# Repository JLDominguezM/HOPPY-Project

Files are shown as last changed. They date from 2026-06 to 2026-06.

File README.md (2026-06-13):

# HOPPY: a one-legged hopping robot







MuJoCo simulation and physical implementation of HOPPY, a one-legged robot that
hops around a rotating boom. The project starts from the
[HOPPY educational kit from the University of Illinois](https://github.com/RoboDesignLab/HOPPY-Project)
(Ramos et al., [arXiv:2010.14580](https://arxiv.org/abs/2010.14580)) and adds a
mechanical redesign of our own: a bird-type leg with a four-bar knee, 3D-printed
parts and PVC tubes.

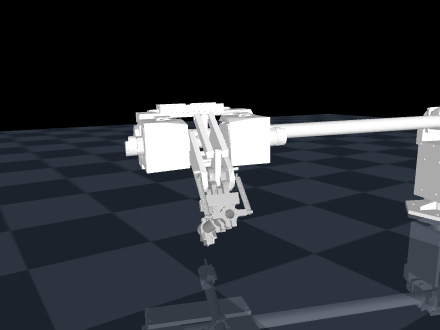
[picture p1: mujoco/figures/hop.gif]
HOPPY hopping in MuJoCo


On hardware the robot hops on its own, continuously: 64 hops logged by its own
telemetry, 0.27 s of flight per hop and roughly 9 cm of apex. That flight time
is close to the simulation (about 0.33 s per hop).

The same controller in simulation, frame by frame, advancing around the post:

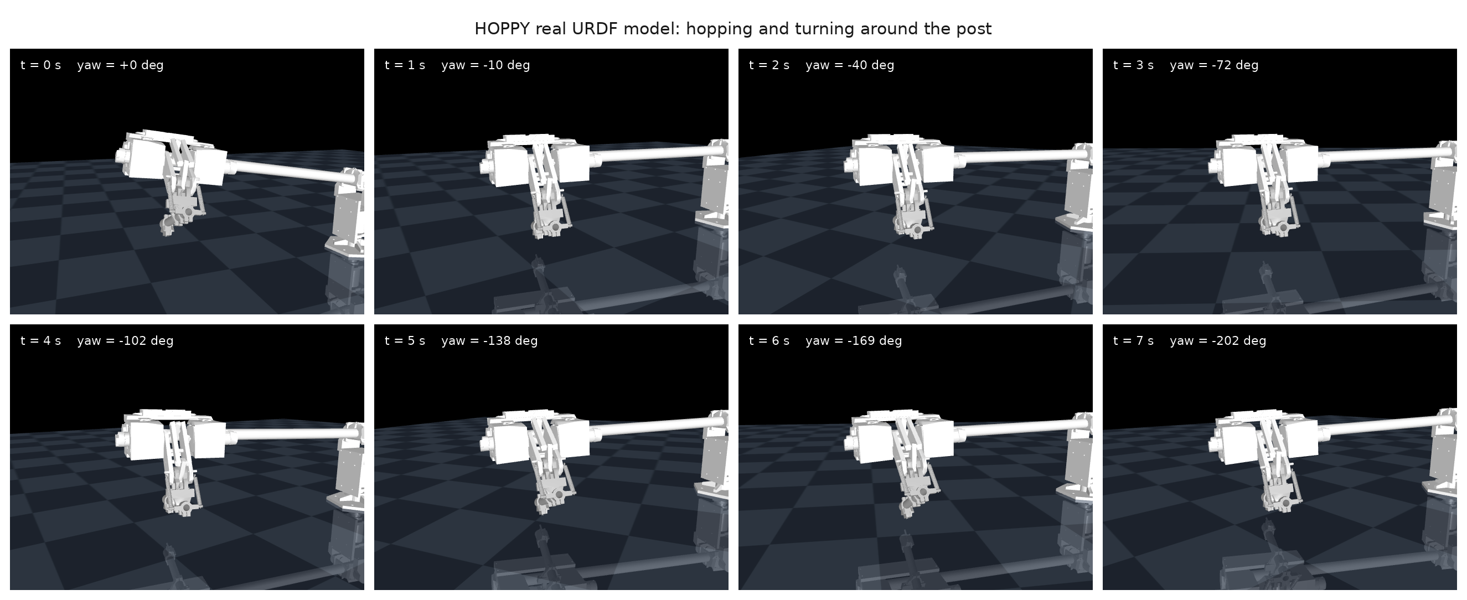
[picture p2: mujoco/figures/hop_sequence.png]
Frames over 7 seconds; the boom advances around the post


## Contents

- [Repository layout](#repository-layout)
- [Simulation (mujoco/)](#simulation-mujoco)
- [Physical parameters and where they come from](#physical-parameters-and-where-they-come-from)
- [Firmware (Microcontroller/)](#firmware-microcontroller)
- [Validation and results](#validation-and-results)
- [Known limitations](#known-limitations)
- [MATLAB simulator on Linux](#matlab-simulator-on-linux)
- [References](#references)
- [Authors](#authors)

## Repository layout

| Folder | Contents |
|---|---|
| [`mujoco/`](mujoco/README.md) | Full MuJoCo simulation: three models, the hybrid controller, a verification suite and the analysis scripts |
| [`Microcontroller/`](Microcontroller/README.md) | C2000 firmware (LaunchPad F28379D) for the physical robot: real-time control at 1 kHz |
| [`CAD/`](CAD/STL_imprimir/README.md) | Redesign assembly (SolidWorks/STEP), nominal parameters and the parts to print |
| [`Simulator_MATLAB/`](Simulator_MATLAB/README.md) | Original MATLAB simulator from the paper, used as the validation reference |

## Simulation (mujoco/)

Requirements: Python 3 with `mujoco`, `numpy` and `matplotlib`.

### The three models

The project grew through three models, each with its own purpose.

| Model | File | Geometry | Hop (steady regime) | Purpose |
|---|---|---|---|---|
| Abstract | `tune_eval.py` | simplified (anchored to `get_params.m`) | body rises 7.2 cm | validation against the paper's MATLAB |
| CAD twin | `twin.py` | dimensions, masses and inertias measured from the CAD | body rises 5.6 cm | structural fidelity to the redesign |
| Real URDF | `hoppy_urdf.py` | exported from SolidWorks (sw2urdf) | foot clears 4.5 cm, turns around the post | the model that runs the robot's controller |

The three share the same controller (`controller.py`), a faithful port of the
paper's MATLAB simulator: a FLIGHT/STANCE state machine at 1 kHz, Cartesian foot
control through the transposed Jacobian in flight, a Bezier reaction-force
profile in stance, a voltage-based actuator model with back-EMF and saturation,
and a velocity estimate from a filtered derivative (encoder emulation).

### Control architecture

The controller is a hybrid state machine. Touchdown and lift-off are detected
from the contact force.

```mermaid
stateDiagram-v2
    [*] --> FLIGHT
    FLIGHT --> STANCE: touchdown (contact force over threshold)
    STANCE --> FLIGHT: liftoff (GRF below 1.5 N, or end of Tst)
```

Every control step runs at 1 kHz, the same loop in simulation and on the
firmware:

```mermaid
flowchart LR
    R[Read encoders] --> V[Filtered velocity, lambda = 10]
    V --> P{Phase}
    P -- FLIGHT --> A[Cartesian foot PD<br/>u = J^T F]
    P -- STANCE --> S[Bezier reaction force<br/>u = -J^T Fx,Fz + soft joint PD]
    A --> M[Voltage, back-EMF and saturation<br/>12 V and 9.2 A]
    S --> M
    M --> W[PWM to the motors]
```

### How to run

| What | Command |
|---|---|
| Watch the real URDF hopping | `python3 view_hop_urdf.py --viewer` |
| Watch the CAD twin hopping | `python3 view_twin.py` |
| Verify the abstract model against MATLAB | `python3 verify.py` |
| Verify the twin | `python3 -c "import twin; from verify import verify; verify(dict(twin.DEFAULTS), mdl=twin)"` |
| Component check of the twin | `python3 twin_check.py` |
| Signals from every phase | `python3 plot_signals.py` |
| Mechanical-model ablation | `python3 ablation.py` |
| Integrator comparison | `python3 integrators.py` |
| Renders and videos (headless) | `MUJOCO_GL=egl python3 render_twin.py` |

`verify.py` is strict on purpose. It asks for real push-off (the contact force
actually loads), a flight phase, no foot flutter and a stable limit cycle. A
metric that only counts foot lift-offs accepts degenerate solutions, such as a
leg that flutters without hopping. This suite does not.

## Physical parameters and where they come from

### Leg geometry (measured from the CAD and the nominal-parameters document)

| Constant | Value | What it is |
|---|---|---|
| `LH` | 0.096 m | thigh length (hip axis to knee axis) |
| `LK` | 0.1545 m | shank length (tube) |
| `DK` | 0.052 m | lateral offset of the tube from the knee axis |
| `LKF` | 0.1635 m | effective shank, `sqrt(LK^2 + DK^2)` |
| `LB`, `DB`, `HB` | 0.687, 0.187, 0.250 m | boom: pivot-to-hip, lateral offset, pivot height |

The redesigned leg is bird-type (mirrored from the original HOPPY): the knee
points backward, and bending it drives the foot forward. The tube never lines up
with the thigh; at full extension it already sits at about 134 degrees to it.

### Actuators (goBILDA 5202 datasheet, Yellow Jacket series)

| Constant | Value | Reason |
|---|---|---|
| `NH` | 26.9 | hip motor reduction |
| `NK` | 28.8 | effective knee reduction (the encoder scale turns the physical 26.9 into an effective 28.8, which matches the kit's nominal document) |
| `Rw` | 1.3 ohm | armature resistance |
| `kT` | 0.0135 N m/A | torque constant |
| `kv` | 0.0186 V s/rad | back-EMF constant |
| `VMAX`, `IMAX` | 12 V, 9.2 A | real electrical limits; they set the maximum torque kT * N * IMAX (3.3 to 3.6 N m per joint) |

Two effects follow from these constants, and the simulation models both
explicitly.

- **Reflected rotor inertia** (`armature = N^2 * Ir`, with `Ir = 7e-6 kg m^2`).
  Without it the accelerations are unrealistic: the ablation shows the robot
  "hops" 67 percent higher when armature is removed.
- **Equivalent actuator damping** (`damping = 0.5 * kT^2 * N^2 / Rw`). This is
  the motor's electrical dissipation reflected to the joint. The 0.5 keeps it
  from double-counting the dissipation the voltage model already adds. It is not
  a hand-tuned number; it comes from the electrical model.

Saturation is not a torque clip. The controller turns desired torque into
voltage (`V = Rw/(kT N) tau + kv N qdot`), clips that to 12 V, computes the
current against the back-EMF, clips it to 9.2 A, and only then gets the applied
torque. The limit therefore depends on speed, the same way it does in the real
motor.

### Knee spring

The real robot carries two tension springs (Ks = 1.67 kN/m, L0 = 80 mm) in a
series-elastic arrangement through the four-bar. In the model this is a joint
spring (`stiffness` plus `springref` at the knee). A faithful series-elastic
spring leaves the knee almost rigid under this controller (the paper uses a
controller designed to exploit it). The trade-off is documented, and the
ablation measures the effect of the joint spring that is used.

### Foot-ground contact

| Parameter | Value | Reason |
|---|---|---|
| `solref` | 0.0191 1 | hard contact, no numerical bounce |
| `solimp` | 0.95 0.99 0.001 | sub-millimeter penetration |
| `friction` | 2.0 | the real foot is a rubber tip and must not slip during push-off |
| integrator | `implicitfast`, 1 ms step | integrates the velocity-dependent terms implicitly (damping and armature, exactly what this model adds); `integrators.py` shows that RK4 with the recommended settings produces the same hop |

Touchdown and lift-off are detected from the normal contact force against a
threshold. This is the same criterion the physical robot uses, where the foot
sensor (a SoftPot) was calibrated on the bench: 0 in the air, around 200 when
grazing, 2870 loaded at rest and 4095 at full load, with the threshold at 2048.

### Controller (constants from the paper's MATLAB simulator)

| Constant | Value | Role |
|---|---|---|
| `Kp_sw`, `Kd_sw` | 150, 5 | Cartesian foot PD in flight (N/m, N s/m) |
| `Krh` | 0.10 | Raibert-style foot placement |
| `Tst` | 0.35 s | nominal stance duration |
| `Fz_bz` | [0, 20, 100, 0, 0] | Bezier control points for the vertical force (desired peak 42.8 N) |
| `Fx_bz` | [0, 0, -25, 0, 0] | tangential push; its sign sets the direction of travel |
| `Kp_st`, `Kd_st` | 0.03, 0.08 | soft joint PD in stance (regularizer) |
| blending | 10 ms | flight-to-stance blend so no torque steps appear |
| `lambda` | 10 rad/s | filter for the estimated velocity (encoder emulation) |

## Firmware (Microcontroller/)

Firmware for the LaunchPad F28379D (C2000), built on the original kit example,
running the same controller from the paper at 1 kHz. Toolchain: Code Composer
Studio 12.8, C2000 compiler 22.6, SYS/BIOS. The active file is
`blinky_rtos_flash/cpu01/cpu01_main.c`.

Implementation notes:

- **Bird-type kinematics**: mirrored-branch IK and a polynomial map of the
  four-bar knee, `q_knee = KA e^2 + KB e + KC` with `KA = -0.454`, `KB = -1.534`,
  `KC = 0.80`, calibrated on the bench with a plumb line and photos. The
  mechanism's effective ratio runs from 1.5 at extension to 0.7 at flexion; the
  negative sign reflects the mirrored morphology. Knee torque is mapped by
  virtual work using the derivative of the same polynomial.
- **Motor electrical model in the loop** (the same equation as the sim): desired
  torque to voltage with back-EMF compensation, then to PWM with the 12 V bus as
  the scale.
- **Continuous-hop state machine** (`JUMP_MODE`): touchdown on the foot-sensor
  edge with debounce, Bezier push in stance, early lift-off when the sensor
  unloads, and an aerial recovery to the landing pose.
- **On-board telemetry**, readable live through CCS Expressions: hop counter,
  duration of the last flight (apex height is g t^2 / 8), measured duration of
  the last stance, and the peaks of PWM and knee travel per push.
- Safety: a motor flag, a PWM limit adjustable live, and a startup with inert
  values.

The robot is balanced with a counterweight on the boom (5 kg at 19 cm in the
current setup), tuned with the float-point method: find the distance that leaves
the boom neutral, then mount the weight at about 76 percent of it, because a full
balance leaves the leg with no weight to load it.

## Validation and results

- **Against the paper's MATLAB**: the `verify.py` suite passes 12 of 12 checks,
  reproducing the behavior of the original simulator.
- **Ablation** (`mujoco/figures/ablation.png`): measures the effect of armature,
  damping, spring and saturation on the hop. Without saturation the ideal
  actuator asks for 13.2 A against the 9.2 A the motor actually has.
- **On hardware**: autonomous continuous hopping in place, 64 hops logged, 0.27 s
  of flight per hop, motors working inside their limits.

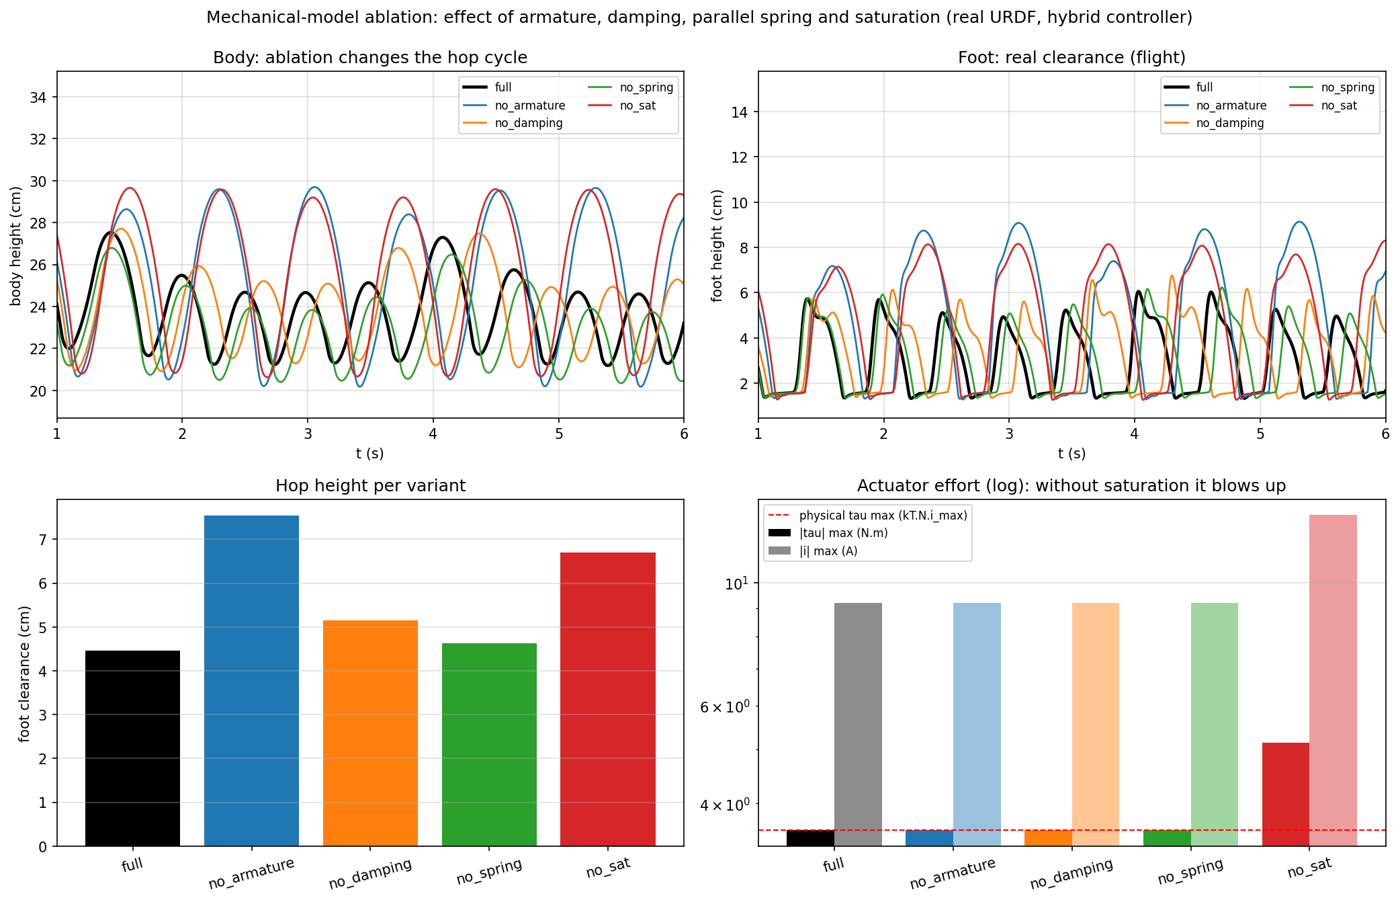
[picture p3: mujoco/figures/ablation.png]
Mechanical-model ablation


### Simulation vs hardware

Everything below is measured, not assumed.

| Metric | Simulation | Real robot |
|---|---|---|
| Control loop | 1 kHz | 1 kHz (C2000) |
| Contact detection | GRF over threshold | SoftPot over 2048 |
| Velocity filter | lambda = 10 | lambda = 10 |
| Counterweight moment | 1.00 kg m | 0.95 kg m |
| Flight per hop | about 0.33 s | 0.27 s |
| Continuous hopping | stable limit cycle | 64 hops logged |

## Known limitations

- Travel around the post under the tangential push is limited by the stiffness of
  the gantry post, which moves under the sustained lateral force. This is a
  structural issue, not a control one.
- A faithful series-elastic spring needs a controller designed for it (such as
  the one in the original paper); under this controller the soft joint spring is
  used instead.
- The foot sensor reports the position of the pressure point, not force, so the
  contact threshold was calibrated empirically.

## MATLAB simulator on Linux

The reference simulator runs on MATLAB R2026a:

```bash
cd Simulator_MATLAB
matlab        # inside the interface, run: MAIN
```

## References

- J. Ramos, Y. Ding, Y. Sim, K. Murphy, D. Block. "HOPPY: An open-source kit for
  education with dynamic legged robots". arXiv:2010.14580.
- Original kit and code: [RoboDesignLab/HOPPY-Project](https://github.com/RoboDesignLab/HOPPY-Project).
- MuJoCo and the official MJCF documentation.

### How to cite

A `CITATION.cff` file is included, so GitHub shows a "Cite this repository"
button. In BibTeX:

```bibtex
@software{hoppy_redesign_2026,
  author = {Dom\'inguez Morales, Jos\'e Luis and Tovar Mendoza, H\'ector Eduardo
            and Velarde Barr\'on, Jocelyn Anahid and Llamas Hern\'andez, Paola
            and Mac Beath Mili\'an, Pablo Armando},
  title  = {HOPPY redesign: MuJoCo simulation and physical implementation},
  year   = {2026},
  url    = {https://github.com/JLDominguezM/HOPPY-Project}
}

@article{ramos2020hoppy,
  author  = {Ramos, Joao and Ding, Yanran and Sim, Young-woo and Murphy, Kevin
             and Block, Daniel},
  title   = {{HOPPY}: An open-source kit for education with dynamic legged robots},
  journal = {arXiv preprint arXiv:2010.14580},
  year    = {2020}
}
```

See [NOTICE](NOTICE) for attribution and [LICENSE](LICENSE) for terms of use.

## Authors

Héctor Eduardo Tovar Mendoza, Jocelyn Anahid Velarde Barrón, Paola Llamas
Hernández, José Luis Domínguez Morales, Pablo Armando Mac Beath Milián.

Robotics Implementation, June 2026.

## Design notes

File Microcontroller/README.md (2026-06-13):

# Firmware (TI C2000)

Real-time control firmware for the physical HOPPY, running on a TI LaunchPad
F28379D (C2000 Delfino) under SYS/BIOS. The control loop runs at 1 kHz and is
the same controller as the simulation (see the top-level README and `mujoco/`).

## Layout

- `blinky_rtos_flash/` — the Code Composer Studio project (CPU1 + CPU2).
  - `cpu01/cpu01_main.c` — **the active file**: the full HOPPY controller.
  - `cpu02/` — second core, unused by the controller.
- `cpu01_main_EXAMPLE.c` — the original kit example (motor and sensor test).
- `cpu01_main_PRUEBA_LENTA.c` — a slow bench-test variant, kept for reference.

## Toolchain and hardware

- Code Composer Studio 12.8, TI C2000 compiler 22.6, SYS/BIOS.
- 2x goBILDA 5202 motors driven by VNH5019 H-bridges, quadrature encoders on
  EQEP1/EQEP2, and a SoftPot foot sensor on ADC-D0.

## Build and flash

1. In Code Composer Studio, import `blinky_rtos_flash/` as an existing CCS
   project (File > Import > CCS Projects).
2. Work in `cpu01/cpu01_main.c`. Build it and flash it to the board.
3. Read the live telemetry through CCS Expressions: hop counter, last flight
   time, last stance time, and the PWM and knee-travel peaks.

## What the controller does

`cpu01_main.c` runs a FLIGHT/STANCE state machine at 1 kHz:

- **Flight**: a Cartesian foot PD places the foot at the landing pose.
- **Stance**: a Bezier reaction-force profile pushes off. Touchdown and lift-off
  come from the SoftPot foot sensor (threshold 2048).
- Desired torque is turned into voltage with back-EMF compensation and clipped
  to the 12 V bus, the same actuator model as the simulation.
- Continuous hopping is enabled with `JUMP_MODE`.

## Safety

Read this before powering the motors.

- `MOTORS_OFF` starts at **1**: the controller computes everything but sends
  nothing to the motors. Set it to 0 (live, in Expressions) only when ready.
- `u_lim_test` caps the PWM. Raise it gradually.
- Clamp the leg, or start with a low push force, as the upstream kit warns.

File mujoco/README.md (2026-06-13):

# HOPPY in MuJoCo

Simulation of the HOPPY hopping robot in MuJoCo. Three models share a single
controller, and all of them are checked against the MATLAB reference simulator
in `../Simulator_MATLAB`: a passive gantry plus an active leg, hybrid control at
1 kHz, hard contact and a voltage-based actuator model. The controller is a
faithful port of the MATLAB code, and the abstract model is anchored to
`get_params.m` (masses, inertias, geometry); the boom balance is calibrated so
the gravitational torque matches the MATLAB reference.

## The three models

| Model | File | Geometry | Purpose |
|---|---|---|---|
| Abstract | `tune_eval.py` | simplified, anchored to `get_params.m` | reproduce the paper's MATLAB hop and validate against it |
| CAD twin | `twin.py` | dimensions, masses and inertias measured from the CAD | structural fidelity to the redesign |
| Real URDF | `hoppy_urdf.py` | exported from SolidWorks (sw2urdf) | the model that runs the robot's controller |

All three use `controller.py`. The abstract model uses MuJoCo-specific gains
chosen to match the MATLAB reference hop. The twin and the URDF run the paper's
own constants, the same ones on the physical robot (listed in the top-level
README).

## The shared controller (`controller.py`)

`Hoppy` is the hybrid controller, ported from the MATLAB simulator:

- a FLIGHT/STANCE state machine at 1 kHz;
- a Cartesian foot PD in the hip frame, applied through the transposed Jacobian;
- a Bezier reaction-force profile in stance (vertical force for the hop,
  tangential force for travel around the post);
- a voltage-based actuator model with back-EMF and 12 V / 9.2 A saturation, so
  the torque limit depends on speed;
- a velocity estimate from a filtered derivative of the (quantized) position,
  which emulates the encoder the firmware reads.

## Files

- `tune_eval.py`, `twin.py`, `hoppy_urdf.py`: the three models (each builds its
  MJCF and its parameter set).
- `controller.py`: the shared hybrid controller (`Hoppy`).
- `control.py`: final run of the abstract model, metrics and `figures/results.png`.
- `verify.py`: the verification suite, 12 pass/fail checks plus a comparison
  against the MATLAB reference.
- `twin_check.py`: component-by-component check of the twin.
- `plot_signals.py`: full signal analysis of the twin (`figures/signals.png`).
- `ablation.py`: mechanical-model ablation (`figures/ablation.png`).
- `integrators.py`: implicitfast vs RK4 (`figures/integrators.png`).
- `counterweight.py`: counterweight (float-point balance).
- `render_*.py`, `view_*.py`: offscreen renders/videos and the interactive viewer.

## Usage

```bash
pip install mujoco numpy scipy matplotlib imageio imageio-ffmpeg

python3 control.py                       # abstract model run + figures/results.png
python3 verify.py                        # verification suite (pass/fail + vs MATLAB)
python3 plot_signals.py                  # twin signals -> figures/signals.png
python3 ablation.py                      # ablation -> figures/ablation.png
python3 integrators.py      # integrators -> figures/integrators.png
MUJOCO_GL=egl python3 render_twin.py     # video figures/twin_salto.mp4
python3 view_hop_urdf.py --viewer        # interactive viewer (real URDF)

# MATLAB reference: cd ../Simulator_MATLAB && matlab -batch "export_ref"
```

## Validation

The robot hops, stays stable and travels around the post. `verify.py` checks
this rather than counting foot lift-offs alone: a stance phase that actually
loads (around 27 N) and pushes, a real flight phase, the body rising from the
push (not from floating), the leg staying bent within the reference range, no
flutter (the foot clears more than the body rises), the gantry not collapsing, a
stable limit cycle, travel around the post, and the electrical limits respected.

### Twin signals

`plot_signals.py` records every signal family from a twin run: joint and
Cartesian positions, raw versus filtered velocities, the contact force, the
control torques against their physical limits, and the state machine.

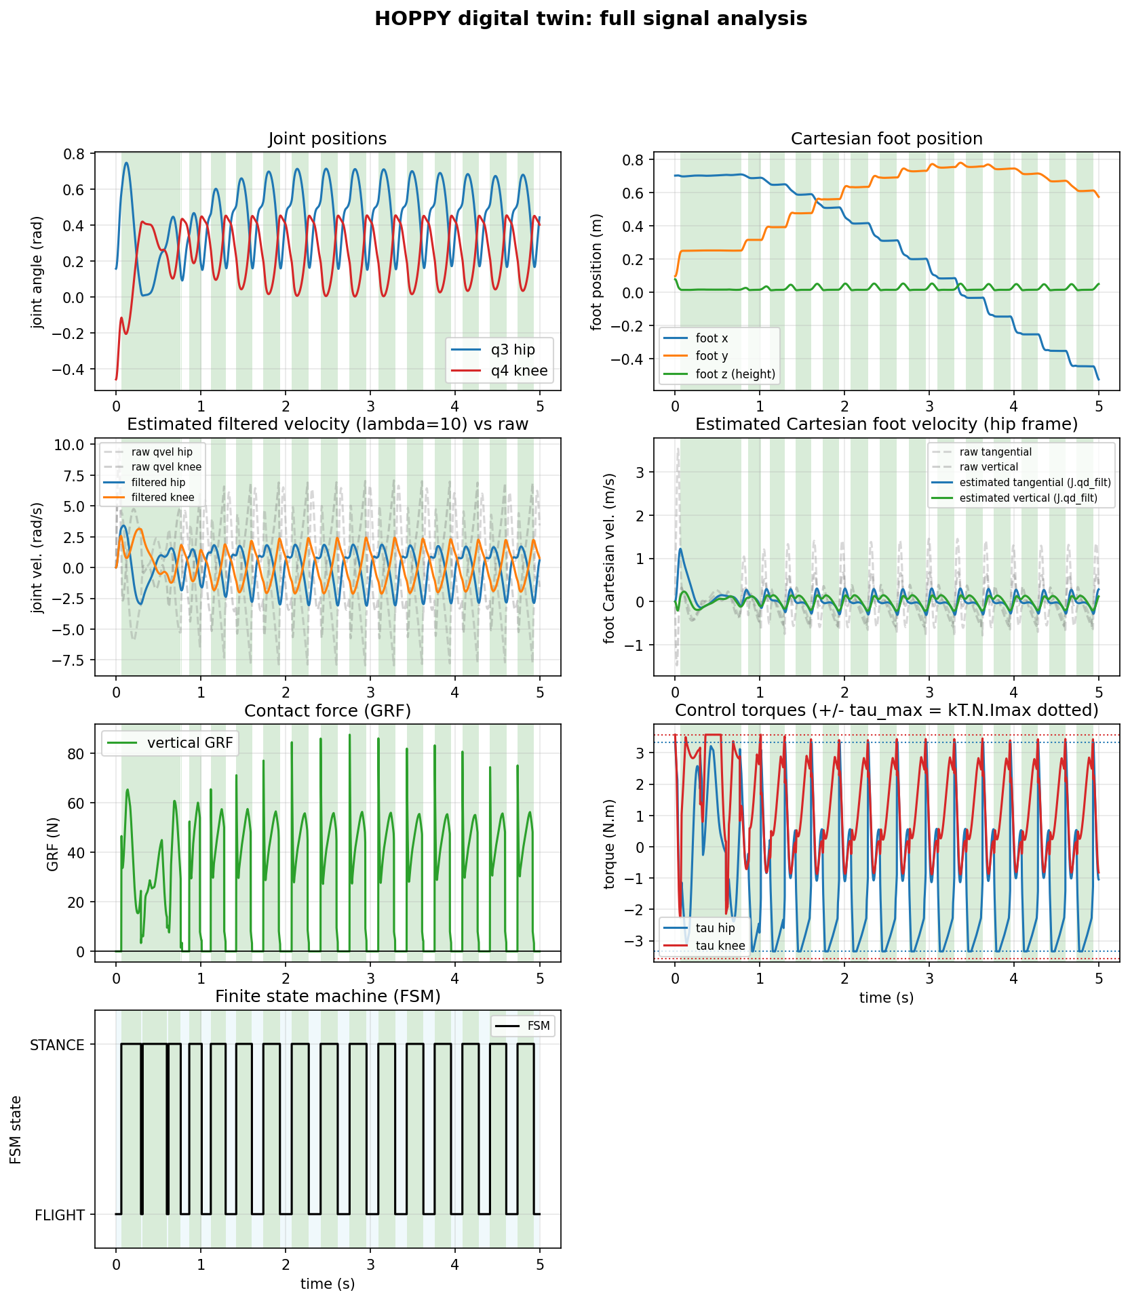
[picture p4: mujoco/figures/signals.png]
HOPPY digital twin signals


### Abstract model against MATLAB

| Metric | MuJoCo | MATLAB |
|---|---|---|
| Min hip height (m) | 0.115 | 0.115 |
| Max hip height (m) | 0.187 | 0.187 |
| Hop amplitude (cm) | 7.2 | 7.2 |
| Frequency (Hz) | 2.5 | 2.2 |
| Stance fraction (%) | 52 | 60 |
| Leg q4 min (rad) | -2.32 | -2.27 |
| Travel around the post | yes (~1.2 turns over the 8 s run) | yes |
| Peak GRF (N) | 84 | 30 |

Same gait (compress, push, fly, land), the same hip amplitude and range
(0.115 to 0.187 m), the leg bent the same way, and travel around the post like
the reference. The remaining differences are minor: frequency about 14 percent
higher (2.5 vs 2.2 Hz) and a slightly smaller stance fraction. The higher peak
GRF is the measured contact impact in MuJoCo's hard contact, not the desired
Bezier force (whose peak is 42.8 N). The abstract-model gains were found by
search over `verify` plus distance to the reference.

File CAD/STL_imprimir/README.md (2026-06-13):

# Parts to print (team redesign)

This project uses the **team redesign** (see `HOPPY_BoM.xlsx`), not the original
goBilda parts from the upstream kit. The parts to print are **IMP-1 ... IMP-30
plus CASE 1/2**.

> An earlier version of this folder held STLs of the original goBilda parts. They
> were removed because the redesign starts from our own geometry, fabricated by
> 3D printing and PVC tubes.

## What is here

- **Print-ready STLs:** the [`STL/`](STL/) folder holds the **33 parts from the
  BOM**, split by material: [`STL/PLA/`](STL/PLA/) (29 parts) and
  [`STL/ABS/`](STL/ABS/) (4 parts: IMP-16, IMP-17, IMP-20, IMP-30). They are
  ready to slice. `IMP-3` and `IMP-6` (the whole-piece versions) and `IMP-23`
  (outside the BOM) are not included.
- **Start with the long parts** (more than 15 h each): IMP-3A, IMP-3B, IMP-6A,
  IMP-6B, IMP-27, IMP-28.

## Motor-shaft coupling: IMP-8 and IMP-10 (two options)

IMP-8 and IMP-10 are the printed parts that transmit motor torque to the leg:
they grip the motor output shaft. With the original parts the coupling stripped
and rounded out under the repeated hop loads, so the motor shaft spun without
driving the leg and the robot could not deliver the full push-off force.

There are two versions of each part. Pick one:

- **Original** (`IMP-8.STL`, `IMP-10.STL`): print and use as-is, no extra hardware.
- **Set-screw version** (`IMP-8_setscrew.STL`, `IMP-10_setscrew.STL`): instead of
  relying on the printed bore, these seat an aluminum hub clamped to the shaft
  with set screws (grub screws), which bite onto the shaft and hold the torque
  through the hop. Use this version **only if you have that aluminum set-screw
  coupler** (the part on the right in the photo below). This is the version that
  fixed the stripping on our robot.

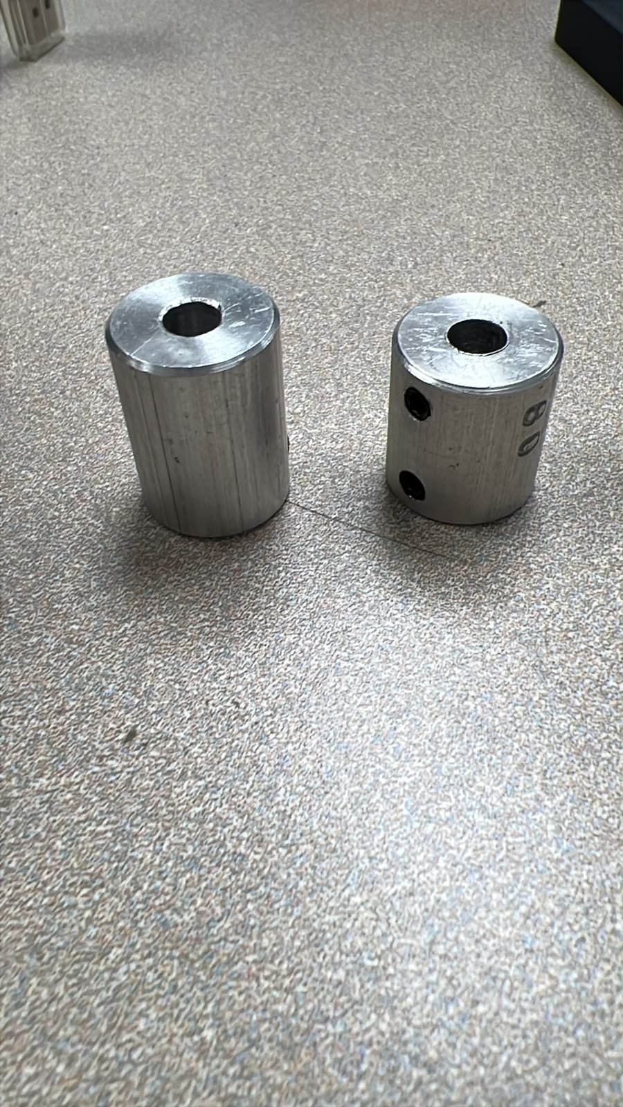
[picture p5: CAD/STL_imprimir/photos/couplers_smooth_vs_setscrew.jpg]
Original smooth coupler on the left (it slipped); the set-screw coupler on the right is the hardware the set-screw version needs


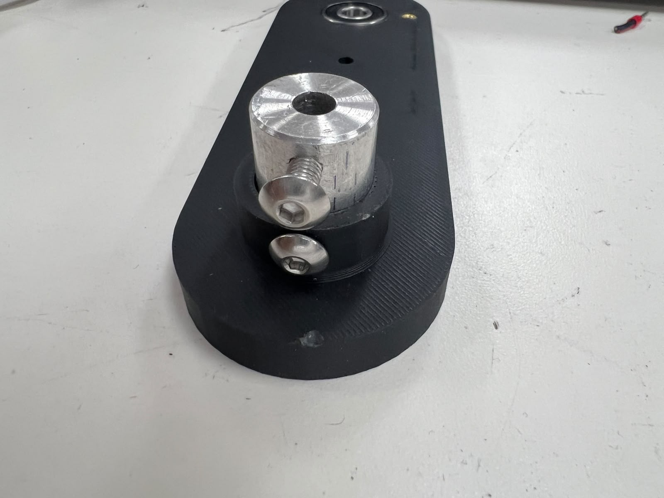
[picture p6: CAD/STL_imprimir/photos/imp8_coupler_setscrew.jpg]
The set-screw coupler seated in the printed IMP-8 part


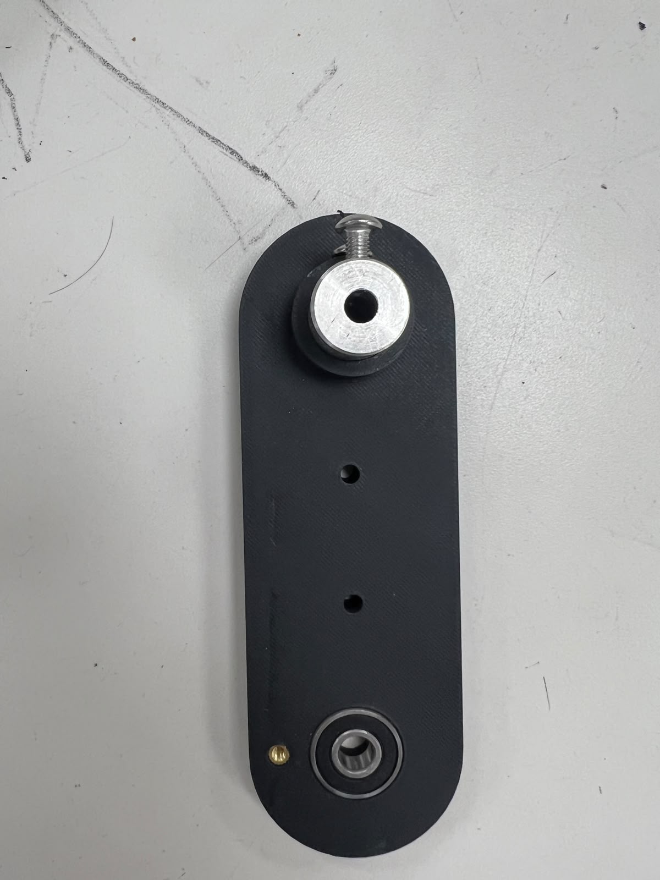
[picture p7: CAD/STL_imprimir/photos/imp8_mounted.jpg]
IMP-8 assembled: the set-screw coupler on the motor shaft, joint bearing below


## Print summary (from the BOM)

- **Total:** 33 parts, **49 copies**, about **4.27 kg** of filament and **240 h**
  of printing.
- Most parts are **PLA**. In **ABS**: IMP-16, IMP-17, IMP-20, IMP-30.
- Long parts (spread them across printers): IMP-3A/3B and IMP-6A/6B (about 22 h
  each), IMP-27 (about 18 h), IMP-28 (about 15.5 h).
- **IMP-8 and IMP-10 come in two versions** (original and set-screw, see the
  section above). You do not print both: choose **one version of each part**, the
  original, or the set-screw one if you have the aluminum coupler. The totals
  above count one version per part.

## PLA print recommendations

The robot takes impacts on landing, so for PLA:

- Nozzle **210-220 C**, slow perimeters (**30-40 mm/s**), fan **40-70 %**.
- **5 walls**, infill **50-70 %**, 6 top/bottom layers.
- **Print lying down** so the impact runs along the layers and does not
  delaminate.
- M2/M3/M4 heat-set inserts: heat with a soldering iron and press in; do not
  print threads.
- Start tests with a low hop force, and keep spares of the leg parts.

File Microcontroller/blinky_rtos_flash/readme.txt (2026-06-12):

/************************************ CPU1 ************************************/

LED D10 blink 1000ms

print time_counter to LCD every 100ms in SYS/BIOS function

LCD RX --- GPIO56 (SCITXD-C, J5-44)

Motor1 --- GPIO0 (EPWM-1A) 
Motor2 --- GPIO1 (EPWM-1B)

Quadrature encoder counter1 --- J14 - EQEP1A(GPIO20), EQEP1B(GPIO21)
Quadrature encoder counter2 --- J15 - EQEP2A(GPIO54), EQEP2B(GPIO55)

PI for Speed Control

/************************************ CPU2 ************************************/

LED D9 blink 500ms

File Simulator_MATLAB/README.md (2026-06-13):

# MATLAB reference simulator

The original MATLAB simulator of HOPPY from the paper (Ramos, Ding, Kim, Murphy,
Block). It is the reference this project validates the MuJoCo port against: the
hybrid controller in `mujoco/controller.py` is a faithful port of this code.

## Run

```bash
cd Simulator_MATLAB
matlab        # then, inside MATLAB, run: MAIN
```

`MAIN.m` runs the hybrid hopping loop with animation and writes a video.
`video.mp4` is an example output.

## Validation against MuJoCo

`export_ref.m` runs the same loop without animation and writes the reference
trajectory to `../mujoco/ref_matlab.csv`. The MuJoCo suite (`mujoco/verify.py`)
compares against that file.

```bash
matlab -batch "export_ref"
```

## Layout

- `MAIN.m` — entry point (hybrid hopping loop and animation).
- `export_ref.m` — dumps the reference trajectory for the MuJoCo comparison.
- `fcns/` — dynamics, contact events, impact map, Bezier utilities and the
  physical parameters (`get_params.m`).
- `gen/` — generated kinematics and dynamics functions.
- `Code_Instructions.pdf` — the upstream walkthrough of the simulator.

Requires MATLAB (tested on R2026a). This folder is upstream material kept for
reproducibility and credit; see [../NOTICE](../NOTICE).

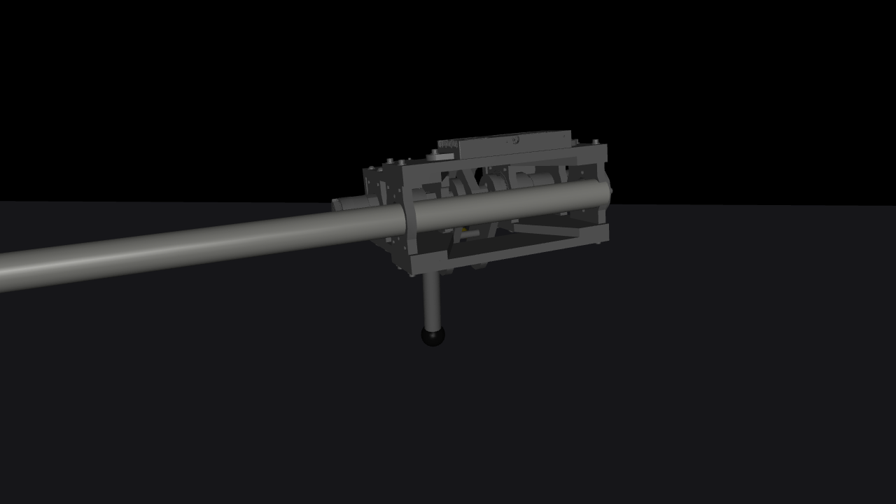
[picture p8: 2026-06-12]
mujoco/figures/twin_hero.png

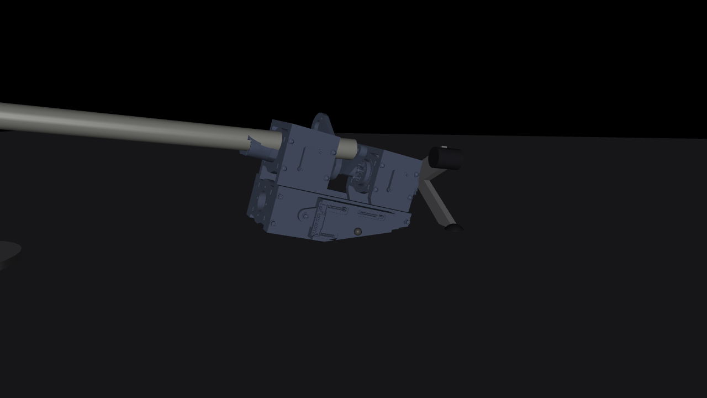
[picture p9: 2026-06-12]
mujoco/figures/hoppy_real.png

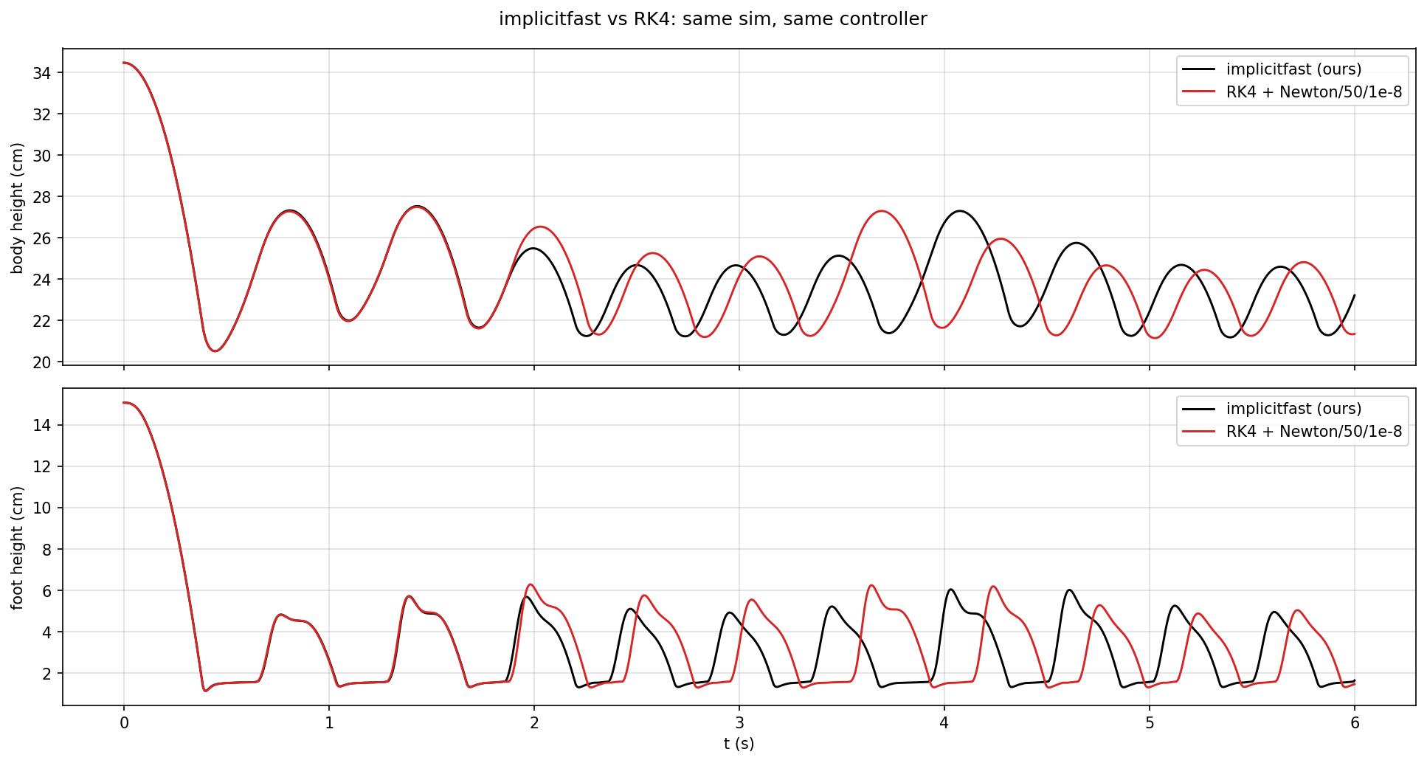
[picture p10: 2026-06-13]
mujoco/figures/integrators.png

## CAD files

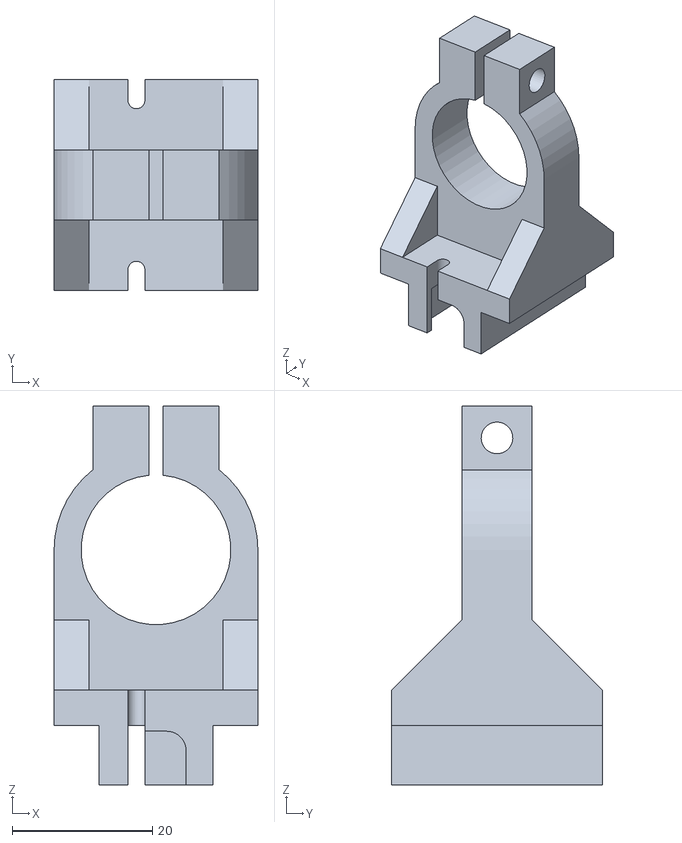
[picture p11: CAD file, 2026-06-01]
CAD/STL_imprimir/STL/ABS/IMP-30.STL
29.0 x 30.0 x 54.0

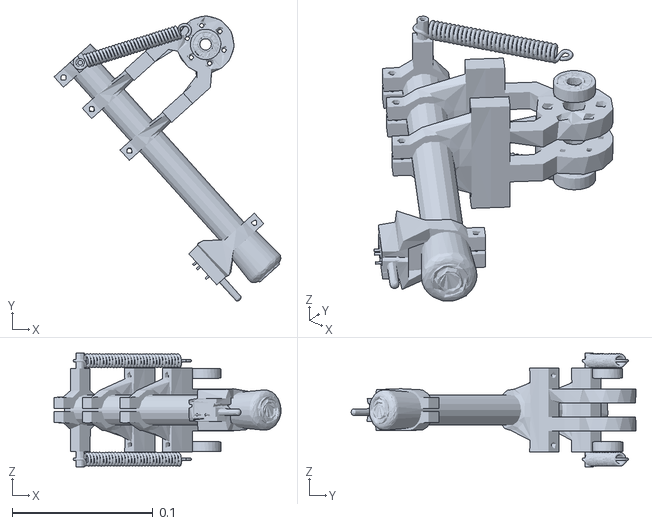
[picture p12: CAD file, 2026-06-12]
mujoco/HOPPY-E0-final/meshes_mj/Link4.STL
0.161 x 0.203 x 0.081

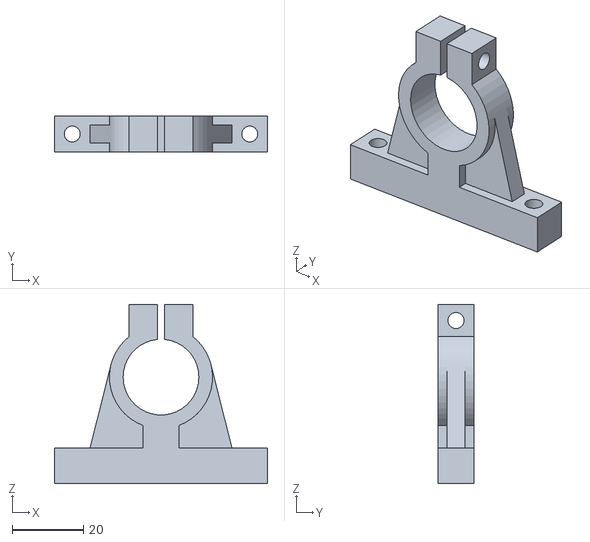
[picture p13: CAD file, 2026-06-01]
CAD/STL_imprimir/STL/ABS/IMP-16.STL
60.0 x 10.0 x 50.5

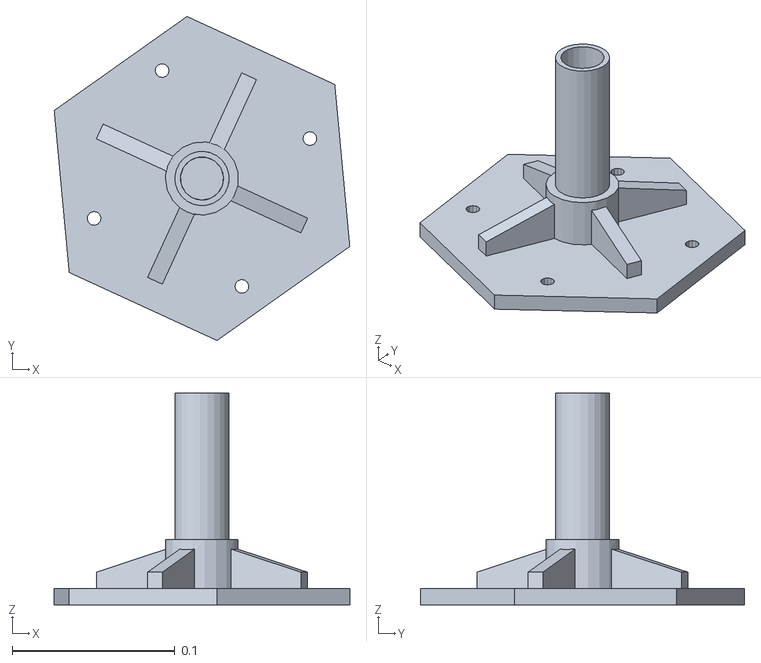
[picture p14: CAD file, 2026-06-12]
mujoco/HOPPY-E0-final/meshes_mj/base_link.STL
0.182 x 0.199 x 0.13

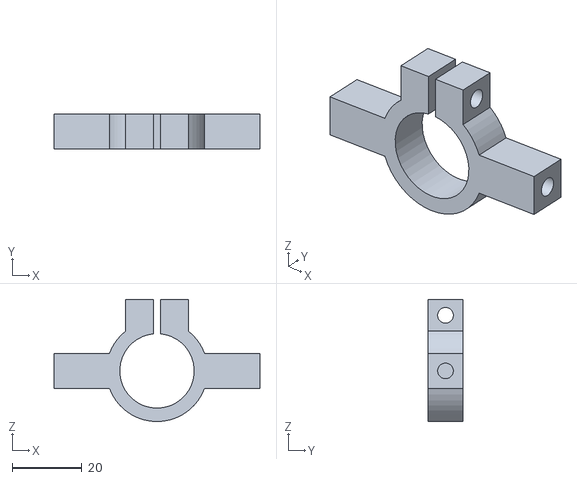
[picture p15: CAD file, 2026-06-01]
CAD/STL_imprimir/STL/ABS/IMP-17.STL
59.1 x 10.0 x 35.0

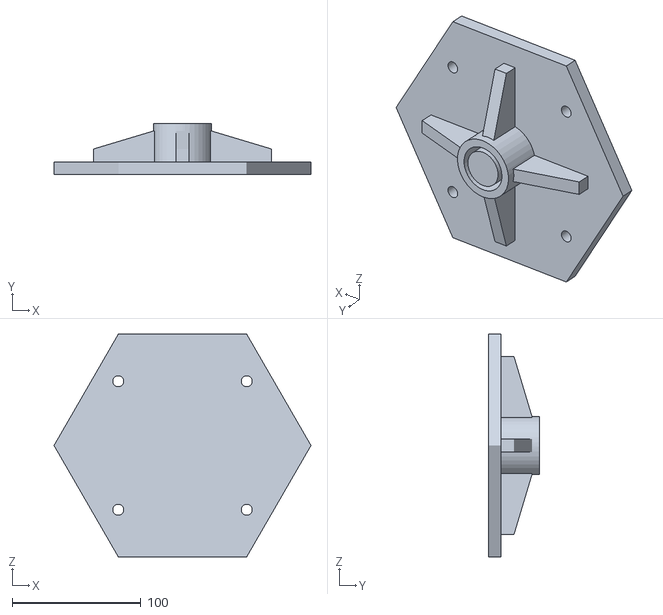
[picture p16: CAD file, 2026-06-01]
CAD/STL_imprimir/STL/PLA/IMP-28.STL
200.0 x 40.0 x 173.2

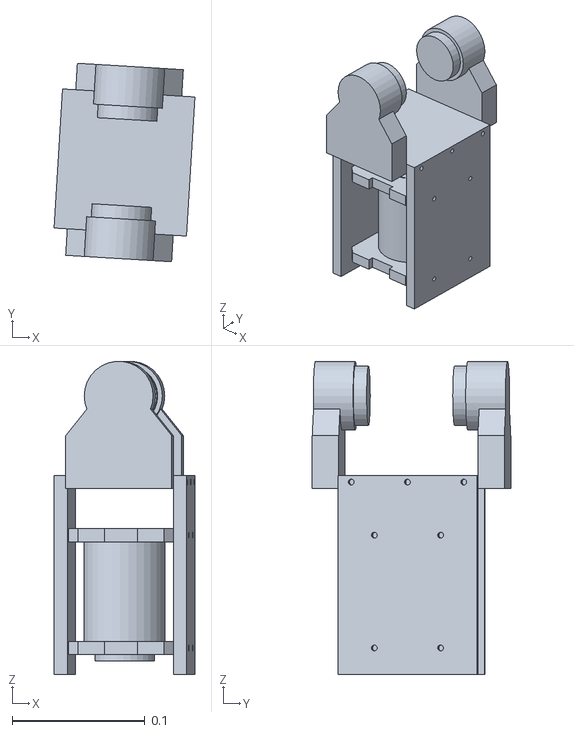
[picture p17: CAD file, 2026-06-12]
mujoco/HOPPY-E0-final/meshes_mj/Link1.STL
0.106 x 0.15 x 0.236

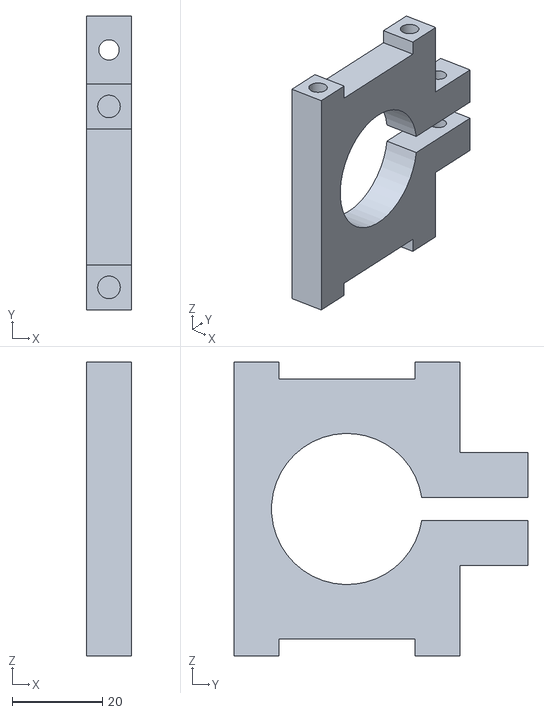
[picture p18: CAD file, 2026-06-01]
CAD/STL_imprimir/STL/ABS/IMP-20.STL
10.0 x 65.0 x 65.0

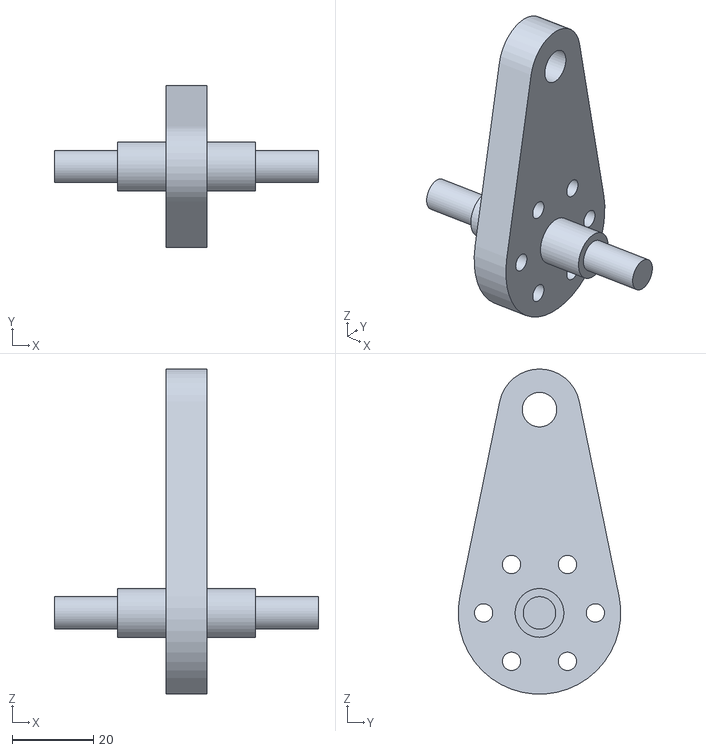
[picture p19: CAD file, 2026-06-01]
CAD/STL_imprimir/STL/PLA/IMP-13.STL
65.0 x 39.9 x 79.9

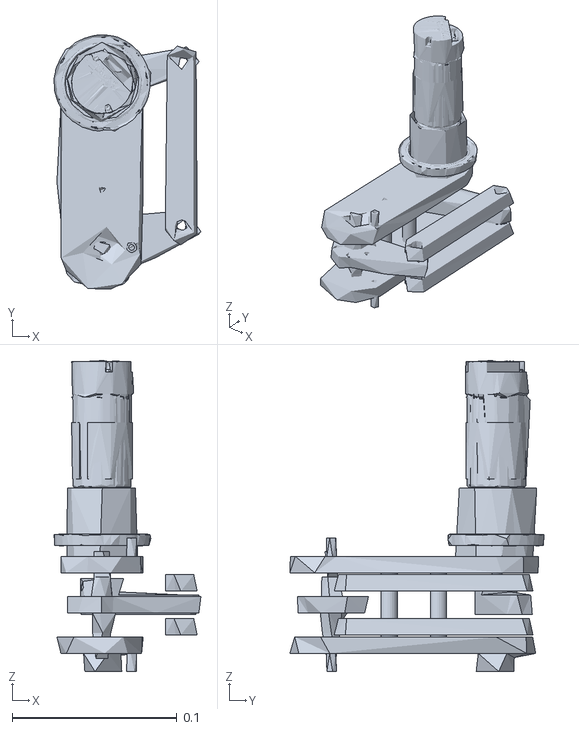
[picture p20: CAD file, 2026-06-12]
mujoco/HOPPY-E0-final/meshes_mj/Link3.STL
0.0893 x 0.155 x 0.189

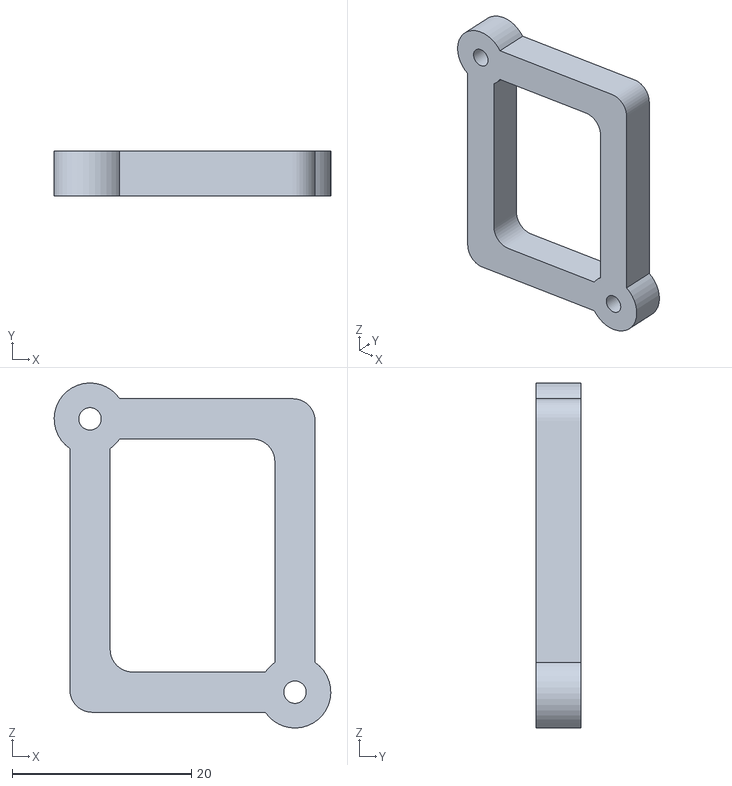
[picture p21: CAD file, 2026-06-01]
CAD/STL_imprimir/STL/PLA/IMP-29.STL
30.9 x 5.00 x 38.5

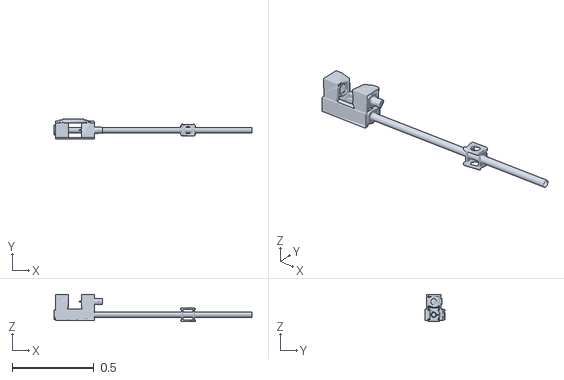
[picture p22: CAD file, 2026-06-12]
mujoco/HOPPY-E0-final/meshes_mj/Link2.STL
1.21 x 0.125 x 0.168

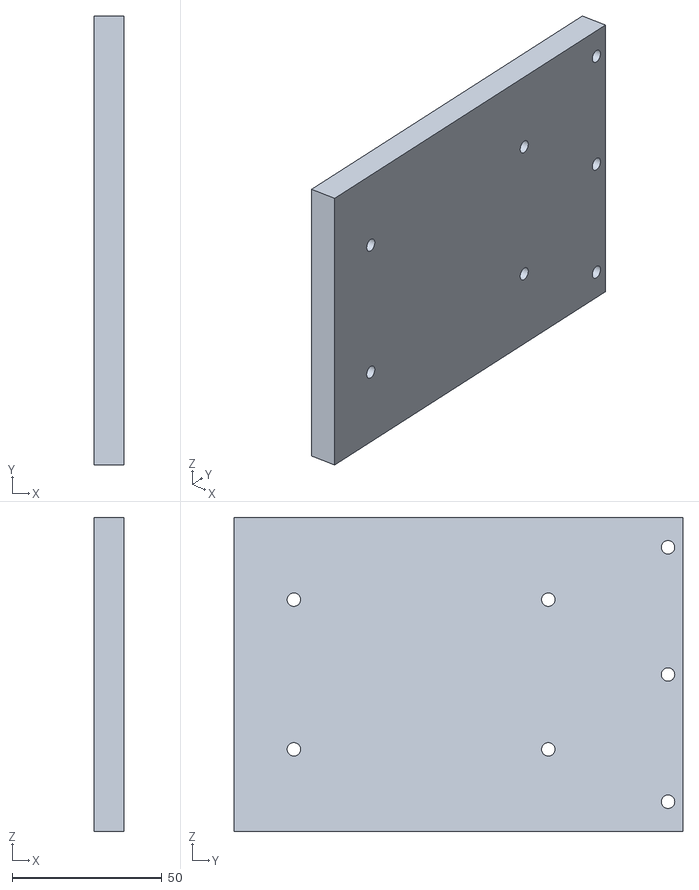
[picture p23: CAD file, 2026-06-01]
CAD/STL_imprimir/STL/PLA/IMP-25.STL
10.0 x 150.0 x 105.0

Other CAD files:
Microcontroller/blinky_rtos_flash/cpu01/src/sysbios/c28_TaskSupport_asm.obj
Microcontroller/blinky_rtos_flash/cpu01/src/sysbios/c28_IntrinsicsSupport_asm.obj
Microcontroller/blinky_rtos_flash/cpu01/src/sysbios/c28_Hwi_disp_asm.obj
Microcontroller/blinky_rtos_flash/cpu01/src/sysbios/c28_Hwi_asm.obj
Microcontroller/blinky_rtos_flash/cpu01/src/sysbios/BIOS.obj
CAD/STL_imprimir/STL/PLA/CASE 1 - F28379D.STL
CAD/STL_imprimir/STL/PLA/CASE 2 - F28379D.STL
CAD/STL_imprimir/STL/PLA/IMP-1.STL
CAD/STL_imprimir/STL/PLA/IMP-10.STL
CAD/STL_imprimir/STL/PLA/IMP-10_setscrew.STL
CAD/STL_imprimir/STL/PLA/IMP-11.STL
CAD/STL_imprimir/STL/PLA/IMP-12.STL
CAD/STL_imprimir/STL/PLA/IMP-14.STL
CAD/STL_imprimir/STL/PLA/IMP-15.STL
CAD/STL_imprimir/STL/PLA/IMP-18.STL
CAD/STL_imprimir/STL/PLA/IMP-19.STL
CAD/STL_imprimir/STL/PLA/IMP-2.STL
CAD/STL_imprimir/STL/PLA/IMP-21.STL
CAD/STL_imprimir/STL/PLA/IMP-22.STL
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

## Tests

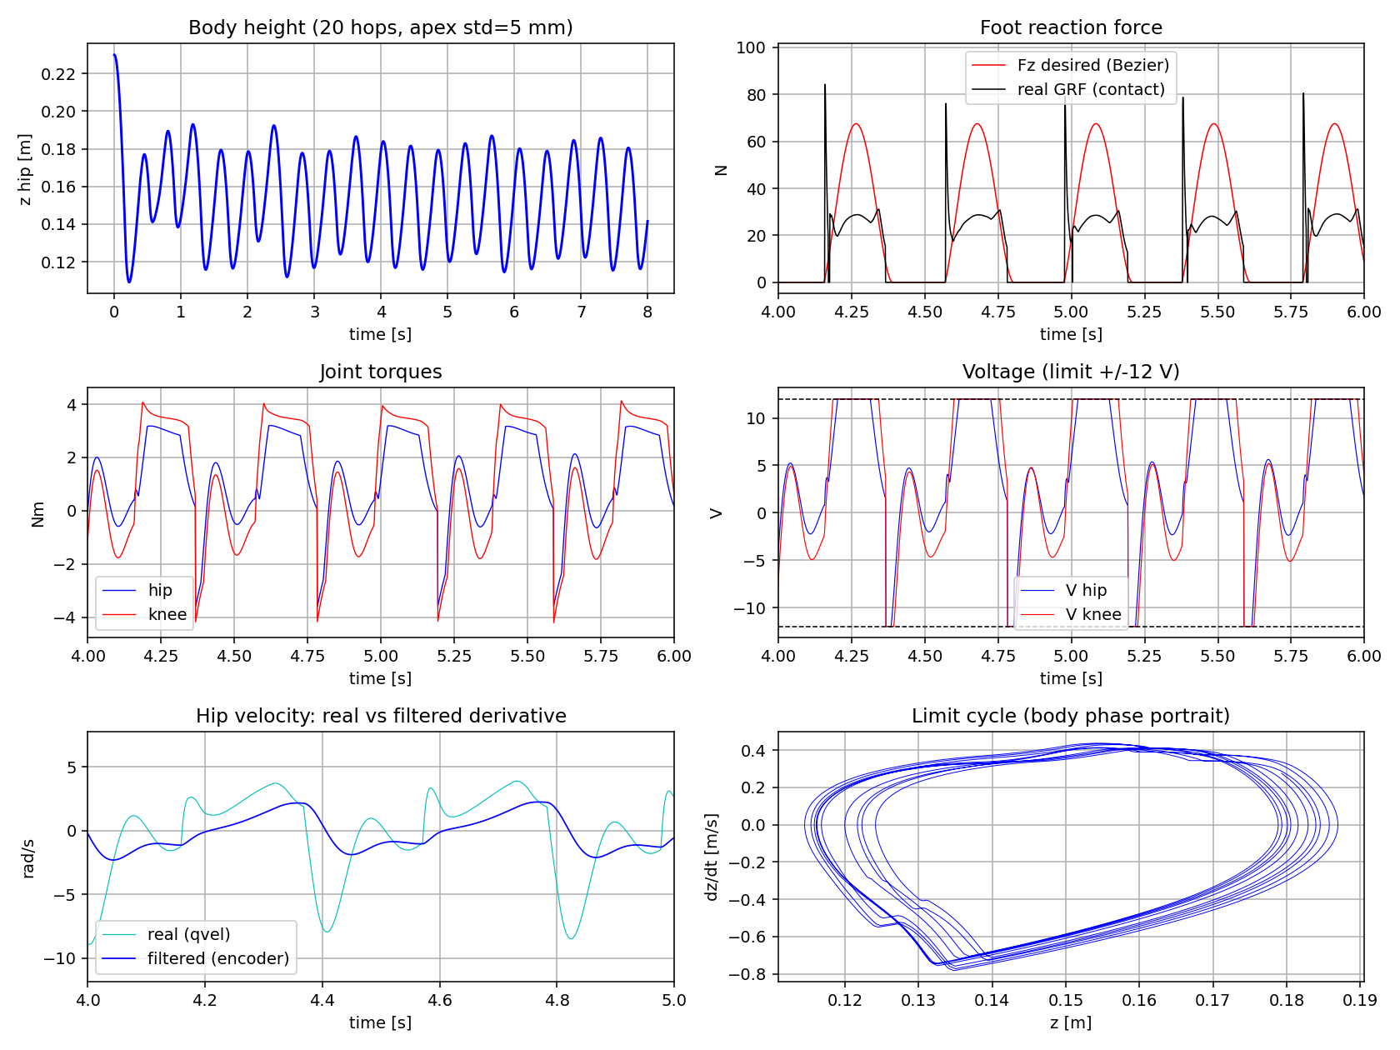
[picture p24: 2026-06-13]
mujoco/figures/results.png

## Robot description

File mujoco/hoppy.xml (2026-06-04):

<mujoco model="hoppy">
  <compiler angle="radian" autolimits="true"/>
  <option timestep="0.001" integrator="implicitfast" gravity="0 0 -9.81"/>
  <default>
    <joint damping="0"/>
    <geom contype="0" conaffinity="0"/>
    <default class="contact">
      <geom contype="1" conaffinity="1" solref="0.002 1" solimp="0.95 0.99 0.001" friction="2.0 0.1 0.1"/>
    </default>
  </default>
  <worldbody>
    <light pos="0 0 2" dir="0 0 -1"/>
    <geom name="floor" class="contact" type="plane" size="3 3 0.1" rgba="0.8 0.8 0.8 1"/>
    <geom name="post" type="cylinder" fromto="0 0 0 0 0 0.2" size="0.02" rgba="0.2 0.2 0.2 1"/>
    <body name="link1" pos="0 0 0.2">
      <joint name="theta1" type="hinge" axis="0 0 1"/>
      <inertial pos="0 0 0" mass="0.268" diaginertia="0.00115952 0.00104649 0.00030518"/>
      <geom type="box" size="0.02 0.02 0.02" rgba="0.4 0.4 0.8 1"/>
      <body name="link2" pos="0 0 0">
        <joint name="theta2" type="hinge" axis="0 1 0"/>
        <inertial pos="-0.25 0 0" mass="0.15" diaginertia="0.002 0.05 0.05"/>
        <geom type="cylinder" fromto="-0.45 0 0 0.556 0 0" size="0.008" rgba="0.7 0.7 0.2 1"/>
        <body name="cuerpo_cadera" pos="0.556 0 0">
          <inertial pos="0 0 0" mass="1.2" diaginertia="0.002 0.002 0.002"/>
          <geom type="box" size="0.03 0.03 0.03" rgba="0.9 0.7 0.1 1"/>
        </body>
        <body name="contrapeso" pos="-0.45 0 0">
          <inertial pos="0 0 0" mass="2.1" diaginertia="0.003 0.003 0.003"/>
          <geom type="cylinder" fromto="0 -0.02 0 0 0.02 0" size="0.05" rgba="0.5 0.5 0.5 1"/>
        </body>
        <body name="link3" pos="0.556 0 0">
          <joint name="theta3" type="hinge" axis="0 1 0" armature="0.005065269999999999"/>
          <inertial pos="0.048 0 0.077" mass="0.656" diaginertia="0.0008211 0.00235762 0.0016834"/>
          <geom type="capsule" fromto="0 0 0 0 0 -0.096" size="0.012" rgba="0.8 0.3 0.3 1"/>
          <body name="link4" pos="0 0 -0.096">
            <joint name="theta4" type="hinge" axis="0 1 0" armature="0.00580608" stiffness="3.0" springref="-1.5708"/>
            <inertial pos="0.002 0.021 0.145" mass="0.149" diaginertia="0.00039424 0.00032191 0.00010442"/>
            <geom type="capsule" fromto="0 0 0 0 0 -0.1545" size="0.010" rgba="0.3 0.3 0.8 1"/>
            <geom name="foot" class="contact" type="sphere" pos="0 0 -0.1545" size="0.012" rgba="0.1 0.1 0.1 1"/>
            <site name="foot_site" pos="0 0 -0.1545" size="0.005"/>
          </body>
        </body>
      </body>
    </body>
  </worldbody>
  <actuator>
    <motor name="hip" joint="theta3" gear="1" ctrlrange="-100 100"/>
    <motor name="knee" joint="theta4" gear="1" ctrlrange="-100 100"/>
  </actuator>
  <sensor>
    <framepos name="foot_pos" objtype="site" objname="foot_site"/>
    <touch name="foot_touch" site="foot_site"/>
  </sensor>
</mujoco>

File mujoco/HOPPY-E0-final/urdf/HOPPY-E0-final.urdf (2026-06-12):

<?xml version="1.0" encoding="utf-8"?>
<!-- This URDF was automatically created by SolidWorks to URDF Exporter! Originally created by Stephen Brawner (brawner@gmail.com) 
     Commit Version: 1.6.0-4-g7f85cfe  Build Version: 1.6.7995.38578
     For more information, please see http://wiki.ros.org/sw_urdf_exporter -->
<robot name="HOPPY-E0-final">
  <link name="base_link">
    <inertial>
      <origin xyz="-2.22044604925031E-16 2.22044604925031E-16 0.0166702186685954" rpy="0 0 0" />
      <mass value="0.384124731516097" />
      <inertia ixx="0.000672971196790525" ixy="-2.26750719979976E-19" ixz="-1.73448497503738E-19" iyy="0.000672971196790525" iyz="3.27058617239314E-19" izz="0.00117890270638154" />
    </inertial>
    <visual>
      <origin xyz="0 0 0" rpy="0 0 0" />
      <geometry>
        <mesh filename="package://HOPPY-E0-final/meshes/base_link.STL" />
      </geometry>
      <material name="">
        <color rgba="1 1 1 1" />
      </material>
    </visual>
    <collision>
      <origin xyz="0 0 0" rpy="0 0 0" />
      <geometry>
        <mesh filename="package://HOPPY-E0-final/meshes/base_link.STL" />
      </geometry>
    </collision>
  </link>
  <link name="Link1">
    <inertial>
      <origin xyz="1.19034530232653E-06 -7.23296036397869E-08 0.110976967027509" rpy="0 0 0" />
      <mass value="1.05188637341997" />
      <inertia ixx="0.00157409752553005" ixy="-2.30264901563404E-05" ixz="1.57979804128911E-08" iyy="0.00119664916196974" iyz="-9.61520238559879E-10" izz="0.000930447203472101" />
    </inertial>
    <visual>
      <origin xyz="0 0 0" rpy="0 0 0" />
      <geometry>
        <mesh filename="package://HOPPY-E0-final/meshes/Link1.STL" />
      </geometry>
      <material name="">
        <color rgba="1 1 1 1" />
      </material>
    </visual>
    <collision>
      <origin xyz="0 0 0" rpy="0 0 0" />
      <geometry>
        <mesh filename="package://HOPPY-E0-final/meshes/Link1.STL" />
      </geometry>
    </collision>
  </link>
  <joint name="joint1" type="continuous">
    <origin xyz="0 0 0.0400000000000003" rpy="0 0 0" />
    <parent link="base_link" />
    <child link="Link1" />
    <axis xyz="0 0 1" />
    <limit effort="10" velocity="10" />
  </joint>
  <link name="Link2">
    <inertial>
      <origin xyz="-0.513965698728862 0.00163269882169459 -0.00902702628387808" rpy="0 0 0" />
      <mass value="1.87653564029707" />
      <inertia ixx="0.00259304289792656" ixy="2.30641489525691E-07" ixz="-5.30325995302201E-08" iyy="0.063650816029348" iyz="-2.09929753044557E-08" izz="0.0630426597842459" />
    </inertial>
    <visual>
      <origin xyz="0 0 0" rpy="0 0 0" />
      <geometry>
        <mesh filename="package://HOPPY-E0-final/meshes/Link2.STL" />
      </geometry>
      <material name="">
        <color rgba="1 1 1 1" />
      </material>
    </visual>
    <collision>
      <origin xyz="0 0 0" rpy="0 0 0" />
      <geometry>
        <mesh filename="package://HOPPY-E0-final/meshes/Link2.STL" />
      </geometry>
    </collision>
  </link>
  <joint name="joint2" type="revolute">
    <origin xyz="-0.0022744379377535 -0.0374309622113542 0.209999999999982" rpy="1.57079632679489 0.0842181705579344 -0.0606889258397237" />
    <parent link="Link1" />
    <child link="Link2" />
    <axis xyz="0 0 1" />
    <limit lower="-0.5" upper="0.5" effort="10" velocity="10" />
  </joint>
  <link name="Link3">
    <inertial>
      <origin xyz="0.00864427677405932 -0.0327980729698124 0.0561207403472103" rpy="0 0 0" />
      <mass value="0.332207029889933" />
      <inertia ixx="0.00029976944437507" ixy="-3.99833421422015E-06" ixz="9.4651821935288E-07" iyy="7.13012720864306E-05" iyz="2.12558330641571E-06" izz="0.000345362348054635" />
    </inertial>
    <visual>
      <origin xyz="0 0 0" rpy="0 0 0" />
      <geometry>
        <mesh filename="package://HOPPY-E0-final/meshes/Link3.STL" />
      </geometry>
      <material name="">
        <color rgba="1 1 1 1" />
      </material>
    </visual>
    <collision>
      <origin xyz="0 0 0" rpy="0 0 0" />
      <geometry>
        <mesh filename="package://HOPPY-E0-final/meshes/Link3.STL" />
      </geometry>
    </collision>
  </link>
  <joint name="joint3" type="revolute">
    <origin xyz="-0.658499999999595 0 0.0425000000006841" rpy="-1.57079632679491 -0.98517045994532 1.57079632679491" />
    <parent link="Link2" />
    <child link="Link3" />
    <axis xyz="0 0 1" />
    <limit lower="-0.5" upper="0.9" effort="10" velocity="10" />
  </joint>
  <link name="Link4">
    <inertial>
      <origin xyz="-0.0162702842654479 -0.0747424597836208 -0.026039892533797" rpy="0 0 0" />
      <mass value="0.172792936147547" />
      <inertia ixx="0.000104974452802714" ixy="6.65227528700312E-05" ixz="5.43245619386452E-08" iyy="9.28412398234489E-05" iyz="-6.59932494517203E-08" izz="0.000170790486199081" />
    </inertial>
    <visual>
      <origin xyz="0 0 0" rpy="0 0 0" />
      <geometry>
        <mesh filename="package://HOPPY-E0-final/meshes/Link4.STL" />
      </geometry>
      <material name="">
        <color rgba="0.752941176470588 0.752941176470588 0.752941176470588 1" />
      </material>
    </visual>
    <collision>
      <origin xyz="0 0 0" rpy="0 0 0" />
      <geometry>
        <mesh filename="package://HOPPY-E0-final/meshes/Link4.STL" />
      </geometry>
    </collision>
  </link>
  <joint name="joint4" type="revolute">
    <origin xyz="0 -0.1 0.00950000000000006" rpy="-3.14159265358979 0 2.55596678674021" />
    <parent link="Link3" />
    <child link="Link4" />
    <axis xyz="0 0 -1" />
    <limit lower="-1.3" upper="0.4" effort="10" velocity="10" />
  </joint>
</robot>

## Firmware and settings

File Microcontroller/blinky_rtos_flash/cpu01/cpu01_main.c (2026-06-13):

/*
This is the basic starter code for Hoppy's Leg

PLEASE NOTE! This is an example code that is NOT meant to run on the leg. It is meant to show the use of the program
While several functions and tools are included, many are not used in the simple example, but will probably be useful
when making the leg hop. This code should be used to test the motor functionality and as a starting place for writing
further code. The included run is a PD loop stepping the two   !!   DISCONNECTED   !!    motors back and forth.
Please clamp the motors down before testing the code! BE SAFE!

The code is broken into intuitive function blocks. The control loop runs at 1 kHz
Each function the user needs is listed below and well documented. All units should be NMS and rads
The starting point is the following function. This calls everything important.
If you are just gettings started,   !!!   START HERE   !!! and follow the code path down.

    DoEveryMilliSecond_CPU1                 - Line #368


At each time step the following functions are called:
    calculate_traj                          - Line # 208
    update_states                           - Line # 289    
    calculate_control();                    - Line # 322
    prevent_saturation();                   - Line # 342


Additional support functions include:
    get_avg_vel                             - Line # 241
    calculate_traj                          - Line # 208
    init_values                             - Line # 196
    get_phase                               - Line # 180    
    update_jacobian                         - Line # 272    
    pose_to_joint_space                     - Line # 281
    ADCD_ISR                                - Line # 620
    main                                    - Line # 410

OTHER
    - Update Encoder Positions. Search for this line. It will bring you to the point in the main function where
      the encoders are initilazized and offsets are set. This is important for zeroing the home position
                                            - Line # 507

    - Setup contact input. The code automatically reads the analog and the digital contact switch. 
      Further instructions are there. EDIT THIS FUNCTION BASED ON WHAT CONTACT METHOD YOU USE
                                            - Line # 180

    - General Declariation of Variables
                                            - Line # 107-175


If you have any questions, please contact Kevin Murphy or Joao Ramos

Enjoy Hoppy :)

@AUTHOR KEVIN MURPHY, Dan Block
kfmurph2@illinois.edu
*/

#include <math.h>

#include <xdc/std.h>
#include <xdc/runtime/Log.h>
#include <xdc/runtime/Error.h>
#include <xdc/runtime/System.h>

#include <ti/sysbios/BIOS.h>
#include <ti/sysbios/knl/Task.h>
#include <ti/sysbios/knl/Swi.h>
#include <ti/sysbios/knl/Clock.h>
#include <ti/sysbios/knl/Semaphore.h>
#include <ti/sysbios/family/c28/Hwi.h>

#include "F28x_Project.h"
#include "F2837xD_device.h"
#include "F2837xD_Ipc_drivers.h"

/***************************** Start Customized functions **************************/
#include "LCD.h"
#include "F28379D_Serial.h"
#include "F28379D_EPwm.h"     // for PWM signal
#include "F28379D_EQep.h"


//#include "driverlib.h"
//#include "device.h"
/*****************************  End Customized functions  **************************/

/*****************************    Start defined Values    **************************/
#define PI       3.1415926535897932384626433832795
#define TWOPI    6.2831853071795864769252867665590
#define HALFPI   1.570796326794897
/*****************************     End defined Values     **************************/

/*****************************  Start Simunlink plotting  **************************/
int adcb0result = 0; // 16-bit
int adcb1result = 0; // 16-bit
long read_1 = 0; // 32-bit
long read_2 = 0; // 32-bit
void simulink_serial_RXD(serial_t *s, char data);
void pose_to_joint_space(void);   // prototype: calculate_traj calls it before its definition
#ifdef _FLASH
// These are defined by the linker (see device linker command file)
extern unsigned int RamfuncsLoadStart;
extern unsigned int RamfuncsLoadSize;
extern unsigned int RamfuncsRunStart;
#endif
extern eqep_t eqep1;
extern eqep_t eqep2;
/*****************************   End Simunlink plotting   **************************/

/****************************************************** OUR ADDITION START **********************************************************/
/******************************************************  User Definitions  **********************************************************/
// int16_t adcd0result = 0;
// int16_t adcd1result = 0;
int16_t analog_in[4] = {0,0,0,0};   // 16 bit analog between 0-3 V.
                                    // should have following index
                                    // [0] = touch sensor
                                    // [1] = optional th_1 encoder
                                    // [2] = optional th_1 encoder
                                    // [3] = open for user input

int16_t analog_limit = 2048;        // this is a tunable value that use used to measure analog linear contact
                                    // the value should be between 0-4096

//Physical dimensions
float LH = .0960;               // hip length
float DK = .0520;               // Knee offset
float LK = .1550;               // length of shank          !this values can be adjusted by the user!
float LKF;                      // shank effective length
float LHF;                      // Distance between hip and foot

//gains TODO TUNABLE VALUES
float Kp_a[2] = { 3000.,  3000.};   // Positional Gain for motor 1 and motor 2 in aerial phase
float Kd_a[2] = {  200.,   200.};   // Derivative Gain for motor 1 and motor 2 in aerial phase

float Kp_s = 60000.;                // Cartesian Positional Gain for motor 1 and motor 2 in stance phase
float Kd_s = 1000.;                 // Derivative Gain for motor 1 and motor 2 in stance phase

//control effort
float u[2]          = {0.0,  0.0};  // control effort for motor 1 and motor 2

//Joint States
float q_now [2]     = {0.0,  0.0};  // Position of the leg at Current time
float q_prev[2]     = {0.0,  0.0};  // Position of the leg at previous time step
float q_ref [2]     = {0.0,  0.0};  // Reference position for aerial
float err_q [2]     = {0.0,  0.0};  // Positional joint Error at current time step

float qdot_now [2]  = {0.0,  0.0};  // Current Joint Velocities
float qdot_prev[2]  = {0.0,  0.0};  // Previous Joint Velocities

//Cartesian States
float pos_des [2] = {0.0,   0.0};   // desired Cartesian position
float pos_now [2] = {0.0,   0.0};   // Current Cartesian position
float err_pos [2] = {0.0,   0.0};   // Positional Error at current time step
float vel_des [2] = {0.0,   0.0};   // desired Cartesian velocity
float vel_err [2] = {0.0,   0.0};   // Cartesian velocity error

// velocity filtering
int horizon = 3;
float vel_avgs[2][3];//YOU MUCH COPY THE HORIZON VALUE TO THE COL(2nd) ARRAY DIMENSION

//Switches
int phase = 1;  // Flag to tell which controller.
                //0 = aerial phase, 1 = stance phase

// Encoders
float enc_offset[2] = {0.0,0.0};    // offset for zeroing the encoders. Initialized in the original read,
                                    //so dont touch HERE. Check out  "Update Encoder Positions" in the Main function

//control Values
float T = 0.001;                    // sampling period in second. This should remain const
float J [2][2];                     //Jacobian

//Misc
long int cnt        = 0;            // time counter

// Temp trajectory vars. These are used in the given example trajectory. You can delete
int posref1dir = 0; // TODO comment out later - just used in initial demo
int posref2dir = 0; // TODO comment out later - just used in initial demo

/****** SLOW LEG TEST - hold it in the air ******/
int   MOTORS_OFF = 1;            // 1 = only checks the IK (q_ref) without moving; 0 = moves the leg
                                 // (starts at 1 for safety: set it to 0 LIVE in Expressions)
// ===== goBILDA MOTOR MODEL (paper Eq.18; used by prevent_saturation) =====
// u[] is REAL TORQUE in N*m and prevent_saturation converts it to voltage:
// V = Rw/(kT*N)*u + kv*N*qdot_f. The old example mapping (10/64.125) treated
// "64 N*m" as full pwm, but physically full pwm = 12 V = ~3.4 N*m at stall
// -> it sent ~5% of the voltage for the real MATLAB torques (the push was not felt).
float Rw = 1.3;                  // armature resistance (ohm)
float kT = 0.0135;               // torque constant (N*m/A)
float kv = 0.0186;               // back-EMF constant (V*s/rad)
float NH = 26.9;                 // hip reduction (rotor -> shaft = units of q_now[0])
float NK = 28.8;                 // EFFECTIVE knee reduction in units of e (the 806.4 scale
                                 // of eqep2 makes the physical 26.9 read as 28.8 = the PDF's N_K)
float VMAX = 12.0;               // driver bus: pwm 10 = 12 V
// Bench PD gains, NOW IN N*m/rad: {20.9, 30.9} = the EXACT equivalents of the
// {400, 600} verified on the bench with the old mapping (same pwm per radian of error).
float Kp_test[2] = {20.9, 30.9};
float Kd_test[2] = { 0.0,  0.0}; // D = 0; with the qdot_f filter it can be raised (0.26 = the old "5")
float u_lim_test = 4.0;          // pseudo-pwm limit (of 10). Raise it live if the knee falls short
float ramp_rate  = 0.15;         // rad/s -> VERY slow (no longer used in flight)
// ===== REAL LEG MORPHOLOGY (clarified, see HANDOFF_FIRMWARE.md) =====
// The leg is BIRD-TYPE (mirrored from the original HOPPY): the "knee" points BACK and
// FLEXING the knee (more negative e) drives the foot FORWARD (+x). Also the tube is
// NEVER aligned with the thigh: at full extension it already sits ~46 deg forward.
// ZERO POSE (reachable and repeatable): THIGH VERTICAL (plumb it with a phone on the plates)
// + knee at its EXTENSION STOP (no spring fighting). There QPOSCNT=0 is written.
// HIP: +q0 = thigh forward. Zero offset = 0 (thigh vertical AT zero).
float beta_off   = 0.0;
// KNEE - FOUR-BAR MAP:  q1_FK = KA*e^2 + KB*e + KC,  e = q_now[1] (encoder).
// q1_FK = effective knee->foot angle relative to the thigh, FORWARD positive. Flexing
// (e<0) INCREASES q1_FK. |KA|,|KB| = shape measured in the 4-point calibration (the effective
// ratio runs ~1.5 extension -> ~0.7 flexion); sign flipped by the mirrored morphology.
// KC = q1_FK at zero (~+0.80 = the ~46 deg of the tube + the foot's DK offset): TUNE with a plumb line.
float KA = -0.454;
float KB = -1.534;
float KC = 0.80;
float q_fk[2] = {0.0, 0.0};   // REAL FK angles (for kinematics/Jacobian); q_now stays in encoder units
// Flight trajectory, tunable LIVE (calculate_traj recomputes pos_des every ms with THESE):
float traj_amp   = 0.00;    // tangential sweep amplitude (m). 0 = foot STILL at traj_x0
                            // (starts at 0 = calibration mode; raise to 0.05 LIVE for the sweep)
float traj_x0    = 0.00;    // sweep center (m). + = forward
float traj_depth = -0.22;   // foot depth below the hip (m)
long  traj_T     = 8000;    // cycle period (ms)
// DIRECT JOINT MODE (calibration): q_ref = q_test as-is (ENCODER units), no IK.
// To measure the knee four-bar effective ratio with the hip held still.
int   JOINT_MODE = 0;
float q_test[2]  = {0.0, 0.0};
float wp_hold    = 2.0;          // s at each pose
#define NWP 2
float wp[NWP][2] = {
  { 0.000,  0.000},   // home (leg extended)
  { 0.524, -1.000},   // crouch: hip +30 deg, knee -57 deg (moves both together)
};
int   wp_i = 0;  float t_wp = 0.0;
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
int main()
{
#ifdef _FLASH
    memcpy(&RamfuncsRunStart, &RamfuncsLoadStart, (size_t)&RamfuncsLoadSize);
#endif

    // Comment this when use CCS for debugging
    //#ifdef _FLASH
    //// Send boot command to allow the CPU2 application to begin execution
    //IPCBootCPU2(C1C2_BROM_BOOTMODE_BOOT_FROM_FLASH);
    //#else
    //// Send boot command to allow the CPU2 application to begin execution
    //IPCBootCPU2(C1C2_BROM_BOOTMODE_BOOT_FROM_RAM);
    //#endif

#ifdef _FLASH
    InitFlash();
#endif

    // Initialize System Control: PLL, WatchDog, enable Peripheral Clocks
    InitSysCtrl(); // F2837xD_SysCtrl.c

    // Initialize GPIO
    InitGpio(); // F2837xD_Gpio.c

    EALLOW;

    // For CPU1
    // Enable an GPIO OUTPUT on GPIO31, set it high
    GpioCtrlRegs.GPAPUD.bit.GPIO31  = 0;  // Enable pullup on GPIO31
    GpioDataRegs.GPASET.bit.GPIO31  = 1;  // Load output latch
    GpioCtrlRegs.GPAMUX2.bit.GPIO31 = 0;  // GPIO31 = GPIO31
    GpioCtrlRegs.GPADIR.bit.GPIO31  = 1;  // GPIO31 = output

/************************************************* SETTING UP CONTACT SWITCH **************************************************/
    // Enable an GPIO INPUT on GPIO9
    GpioCtrlRegs.GPAPUD.bit.GPIO9     = 0;    // enable pullup on GPIO9
    GpioCtrlRegs.GPAMUX1.bit.GPIO9    = 0;    // Set pin as standard GPIO as opposed to EPWM, etc
    GpioCtrlRegs.GPACTRL.bit.QUALPRD1 = 0x20; // Divide sampling frequency by 32. t_sample/32
    GpioCtrlRegs.GPADIR.bit.GPIO9     = 0;    // GPIO9 = input

/********************************************** END SETTING UP CONTACT SWITCH *************************************************/
    // For CPU2
    // Enable an GPIO output on GPIO34, set it high
    GpioCtrlRegs.GPBPUD.bit.GPIO34   = 0;   // Enable pullup on GPIO3
    GpioDataRegs.GPBSET.bit.GPIO34   = 1;   // Load output latch
    GpioCtrlRegs.GPBDIR.bit.GPIO34   = 1;   // GPIO34 = output

    GpioCtrlRegs.GPBCSEL1.bit.GPIO34 = 2;   // MUX with CPU2
    GpioCtrlRegs.GPBGMUX1.bit.GPIO34 = 0;
    GpioCtrlRegs.GPBMUX1.bit.GPIO34  = 0;

    // Driverlib way for CPU2
    //GpioCtrlRegs.GPBDIR.bit.GPIO34 = 1;   // GPIO34 = output
    //GPIO_SetupPinOptions(34, GPIO_OUTPUT, GPIO_PUSHPULL);
    //GPIO_SetupPinMux(34, GPIO_MUX_CPU2, 0);

    EDIS;

    /***************************** Init Simulink Serial *****************************/
    // GPIO19 - SCIRXDB, GPIO18 - SCITXDB, Simulink plot through SCI-B
    //init_serial(&SerialB, 115200, simulink_serial_RXD);
    init_serial(&SerialA, 115200, NULL);

    /********************************* Init Text LCD *********************************/
    init_serial(&SerialC, 19200, NULL);

    /********************************** Init EPwm1A **********************************/
    init_EPWM1A_GPIO_VNH5019();     // init GPIO0 as EPWM1A (J4-40)
    init_EPWM1A_VNH5019();          // init EPWM1A with a 20KHz carrier frequency PWM signal.
    set_EPWM1A_VNH5019(u[0]);       // set to 0 (50% duty cycle)at the beginning, update in SYS/BIOS

    init_EPWM1B_GPIO_VNH5019();     // init GPIO1 as EPWM1A (J4-39)
    init_EPWM1B_VNH5019();          // init EPWM1B with a 20KHz carrier frequency PWM signal.
    set_EPWM1B_VNH5019(u[1]);       // set to 0 (50% duty cycle)at the beginning, update in SYS/BIOS

    /****************************** Init EQep1 and EQep2 *****************************/
    // J14 - EQEP1A(GPIO20), EQEP1B(GPIO21), J15 - EQEP2A(GPIO54), EQEP2B(GPIO55)

    // 7: total slits of motor's encoder in one revolution
    // 26.9: gear ratio
    // 753.2 = 7 * 26.9 * 4
    // 1: INVERTED polarity (-1 -> 1): the hip encoder read thigh-forward as NEGATIVE
    // 0: start  0 rad
    init_EQEP(&eqep1, EQEP1, 753.2, 1, 0.0);
    EQep1Regs.QPOSCNT = 0;

    // 7: total slits of motor's encoder in one revolution
    // 19.2: gear ratio
    // 1.5 Belt gear ratio
    // 806.4‬ =  7 * 19.2 * 4 * 1.5
    // 1: polarity of motor direction
    // 0: start  0 rad
    init_EQEP(&eqep2, EQEP2, 806.4, 1, 0.0);
    EQep2Regs.QPOSCNT = 0;


    /*********************************************************** Update Encoder Positions **********************************************************/
    //TODO initilaize the encoders by leaving th3 at zero and hold the shank to a desired position.
    float des_th4_offset = 0; //input the desired joint position in Radians

    enc_offset[0] =  0 - read_Enc1();
    enc_offset[1] =    - read_Enc2() + des_th4_offset; // offset is to that the
    q_now[0] = read_Enc1() + enc_offset[0]; // read encoder1 at the beginning, update in SYS/BIOS func
    q_now[1] = read_Enc2() + enc_offset[1]; // read encoder2 at the beginning, update in SYS/BIOS func

    //init global values with/related to function calls
    init_values();

    /******************************************************  NO CODE below here in Main() ******************************************************/

    EALLOW;
        EPwm5Regs.ETSEL.bit.SOCAEN  = 0;    // Disable SOC on A group
        EPwm5Regs.TBCTL.bit.CTRMODE = 3;    // freeze counter
        EPwm5Regs.ETSEL.bit.SOCASEL = 2;    // Select Event when counter equal to PRD
        EPwm5Regs.ETPS.bit.SOCAPRD  = 1;    // Generate pulse on 1st event (“pulse” is the same as “trigger”)
        EPwm5Regs.TBCTR             = 0x0;  // Clear counter
        EPwm5Regs.TBPHS.bit.TBPHS   = 0x00; // Phase is 0
        EPwm5Regs.TBCTL.bit.PHSEN   = 0;    // Disable phase loading
        EPwm5Regs.TBCTL.bit.CLKDIV  = 0;    // divide by 1  50Mhz Clock
        EPwm5Regs.TBPRD             = 50000;// Set Period to 1ms sample.  Input clock is 50MHz.
        // Notice here that we are not setting CMPA or CMPB because we are not using the PWM signal
        EPwm5Regs.ETSEL.bit.SOCAEN  = 1;    //enable SOCA
        EPwm5Regs.TBCTL.bit.CTRMODE = 0;    //unfreeze, and enter up count mode
        EDIS;


    EALLOW;
        //write configurations for all ADCs  ADCA, ADCB, ADCC, ADCD
        AdcaRegs.ADCCTL2.bit.PRESCALE = 6; //set ADCCLK divider to /4
        AdcbRegs.ADCCTL2.bit.PRESCALE = 6; //set ADCCLK divider to /4
        AdccRegs.ADCCTL2.bit.PRESCALE = 6; //set ADCCLK divider to /4
        AdcdRegs.ADCCTL2.bit.PRESCALE = 6; //set ADCCLK divider to /4
        AdcSetMode(ADC_ADCA, ADC_RESOLUTION_12BIT, ADC_SIGNALMODE_SINGLE);  //read calibration settings
        AdcSetMode(ADC_ADCB, ADC_RESOLUTION_12BIT, ADC_SIGNALMODE_SINGLE);  //read calibration settings
        AdcSetMode(ADC_ADCC, ADC_RESOLUTION_12BIT, ADC_SIGNALMODE_SINGLE);  //read calibration settings
        AdcSetMode(ADC_ADCD, ADC_RESOLUTION_12BIT, ADC_SIGNALMODE_SINGLE);  //read calibration settings
        //Set pulse positions to late
        AdcaRegs.ADCCTL1.bit.INTPULSEPOS = 1;
        AdcbRegs.ADCCTL1.bit.INTPULSEPOS = 1;
        AdccRegs.ADCCTL1.bit.INTPULSEPOS = 1;
        AdcdRegs.ADCCTL1.bit.INTPULSEPOS = 1;
        //power up the ADCs
        AdcaRegs.ADCCTL1.bit.ADCPWDNZ = 1;
        AdcbRegs.ADCCTL1.bit.ADCPWDNZ = 1;
        AdccRegs.ADCCTL1.bit.ADCPWDNZ = 1;
        AdcdRegs.ADCCTL1.bit.ADCPWDNZ = 1;
        //delay for 1ms to allow ADC time to power up
        DELAY_US(1000);

        //Select the channels to convert and end of conversion flag
        //Many statements commented out,  To be used when using ADCA or ADCB
        //ADCA
        //AdcaRegs.ADCSOC0CTL.bit.CHSEL = ???;  //SOC0 will convert Channel you choose Does not have to be A0
        //AdcaRegs.ADCSOC0CTL.bit.ACQPS = 14; //sample window is acqps + 1 SYSCLK cycles = 75ns
        //AdcaRegs.ADCSOC0CTL.bit.TRIGSEL = ???;// EPWM5 ADCSOCA or another trigger you choose will trigger SOC0
        //AdcaRegs.ADCSOC1CTL.bit.CHSEL = ???;  //SOC1 will convert Channel you choose Does not have to be A1
        //AdcaRegs.ADCSOC1CTL.bit.ACQPS = 14; //sample window is acqps + 1 SYSCLK cycles = 75ns
        //AdcaRegs.ADCSOC1CTL.bit.TRIGSEL = ???;// EPWM5 ADCSOCA or another trigger you choose will trigger SOC1
        //AdcaRegs.ADCINTSEL1N2.bit.INT1SEL = ???; //set to last SOC that is converted and it will set INT1 flag ADCA1
        //AdcaRegs.ADCINTSEL1N2.bit.INT1E = 1;   //enable INT1 flag
        //AdcaRegs.ADCINTFLGCLR.bit.ADCINT1 = 1; //make sure INT1 flag is cleared
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

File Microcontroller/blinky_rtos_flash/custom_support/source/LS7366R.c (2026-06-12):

#include <F28379D_Coecsl.h>
#include <F28379D_Spi.h>
#include <F28x_Project.h>
#include <LS7366R.h>

#include <ti/sysbios/knl/Swi.h>

/* Swi handle defined in swi.cfg */
extern const Swi_Handle SWI_control;

//init_SPIB_LS7366R(void);
//void SPI_RXint_LS7366R(void);
//Swi_post(&SWI_control);

/*
Two LS7366 chips are interfaced to the F28379D through its SPI serial 
peripheral.

These LS7366 chips are 32 bit counters that count up when the optical 
encoder is turned in the positive direction and count down when turned 
in the opposite direction.

F28379D uses its SPI serial port to read this 32 bit count from each of 
the LS7366 chips.
**/

long SPIbyte1, SPIbyte2, SPIbyte3, SPIbyte4, SPIbyte5; // 4 bytes = 32 bits

long SPIenc1_reading = 0;
long SPIenc2_reading = 0;

int SPIenc_state = 0;
int	SPIenc_state_errors = 0;


void init_SPIB_LS7366R(void) {

    /************** Setup Gpio for chip select **************/

    // Chip select 1 - Gpio130
    // Chip select 2 - Gpio131

    EALLOW;
        // GPIO Port E MUX1 (GPEMUX1) Register
        GpioCtrlRegs.GPEMUX1.bit.GPIO130 = 0;    // Set pin as GPIO
        GpioCtrlRegs.GPEMUX1.bit.GPIO131 = 0;   // Set pin as GPIO

        // GPIO Port E Direction (GPEDIR) Register
        GpioCtrlRegs.GPEDIR.bit.GPIO130 = 1;    // Set GPIO as Output
        GpioCtrlRegs.GPEDIR.bit.GPIO131 = 1;    // Set GPIO as Output

        // GPIO Port E Set (GPESET) Register
        GpioDataRegs.GPESET.bit.GPIO130 = 1;    // Set the output as high, disable LS7366 1
        GpioDataRegs.GPESET.bit.GPIO131 = 1;    // Set the output as high, disable LS7366 2
    EDIS;


    // SPI Configuration Control Register (SPICCR)
    // Put SPI in reset condition (default)
    SpibRegs.SPICCR.bit.SPISWRESET = 0;  // Put SPI in reset

    /*
    This configuration POLARITY = 0, PHASE = 1 is due to default LS7366 setting

    Data is output on rising edge and input on falling edge. When no SPI data is sent,
    SPICLK is at low level. The data input and output edges depend on the value of the
    CLOCK PHASE bit (SPICTL.3) as follows:

    CLOCK PHASE = 0: Data is output on the rising edge of the SPICLK signal;
                     input data is latched on the falling edge of the SPICLK signal

    CLOCK PHASE = 1: Data is output one half-cycle before the first rising edge of the
                     SPICLK signal and on subsequent falling edges of the SPICLK signal;
                     input data is latched on the rising edge of the SPICLK signal
    **/

    // SPI Configuration Control Register (SPICCR)
    SpibRegs.SPICCR.bit.CLKPOLARITY = 0;     // Set for LS7366

    // SPICLK signal delayed by one half-cycle; polarity determined by the CLOCK POLARITY bit
    // SPI Operation Control Register (SPICTL)
    SpibRegs.SPICTL.bit.CLK_PHASE = 1;

    // SPI Configuration Control Register (SPICCR)
    // Set to transmit 8 bits
    SpibRegs.SPICCR.bit.SPICHAR = 7;

    // SPI Operation Control Register (SPICTL)
    // SPI configuraed as a Master
    SpibRegs.SPICTL.bit.MASTER_SLAVE = 1;

    // SPI Operation Control Register (SPICTL)
    // Master/Slave Transmit Enable
    // Enables transmission for the 4-pin option, (MOSI-MISO-SCK-SS)
    // Ensure to enable the receiver SPISTE/ input pin (namely the chip select SS/)
    SpibRegs.SPICTL.bit.TALK = 1;

    // SPI Operation Control Register (SPICTL)
    // This bit controls the SPI's ability to generate a transmit/receive interrupt
    // The SPI INT FLAG bit (SPISTS.6) is unaffected by this bit
    // Disable interrupt
    SpibRegs.SPICTL.bit.SPIINTENA = 0;


    /**************  SPI status register **************/
    /*
    Bit 7 = 1: Clears this bit.
    The RECEIVER OVERRUN Flag bit should be cleared during the interrupt service routine
    because the RECEIVER OVERRUN Flag bit and SPI INT FLAG bit (SPISTS.6) share the same
    interrupt vector. This will alleviate any possible doubt as to the source of the
    interrupt when the next byte is received

    Bit 6 = 1: This bit is cleared in one of three ways:
               Reading SPIRXBUF
               Writing a 0 to SPI SW RESET (SPICCR.7)
               Resetting the system

    Bit 5 = 1: This bit is cleared at reset
    **/
    SpibRegs.SPISTS.all = 0x00E0;   // (0000 0000 1110 0000)

    // SPI Baud Rate Register (SPIBRR)
    // SPI Baud Rate = LSPCLK / (SPIBRR + 1)
    SpibRegs.SPIBRR.bit.SPI_BIT_RATE = 39;          // Divide by 40 - 2.5 Mhz


    /***************** FIFO Settings *****************/

    // SPI FIFO Transmit (SPIFFTX) Register

    // Description: SPI reset
    // SPI FIFO can resume transmit or receive.
    // No effect to the SPI registers bits
    SpibRegs.SPIFFTX.bit.SPIRST = 1;

    // Description: SPI FIFO enhancements enable
    // SPI FIFO enhancements function are enabled
    SpibRegs.SPIFFTX.bit.SPIFFENA = 1;

    // Description: Transmit FIFO reset
    // Write 0 to reset the FIFO pointer to zero, and hold in reset
    SpibRegs.SPIFFTX.bit.TXFIFO = 0;

    // Description: TXFIFO clear
    // Write 1 to clear TXFFINT flag in bit 7 (TXFFINT=0)
    // TXFFINT=0: interrupt has not occured, this is a read-only bit
    SpibRegs.SPIFFTX.bit.TXFFINTCLR = 1;


    /************** SPI FIFO Receive (SPIFFRX) Register **************/

    // Description: Receive FIFO reset
    // Write 0 to reset the FIFO pointer to zero, and hold in reset
    SpibRegs.SPIFFRX.bit.RXFIFORESET = 0;

    // Description: Receive FIFO overflow clear
    // Write 1 to clear RXFFOVF flag in bit 15 (RXFFOVF - receive FIFO overflow flag)
    // RXFFOVF=0: receive FIFO has not overflowed, this is a read-only bit
    SpibRegs.SPIFFRX.bit.RXFFOVFCLR = 1;

    // Description: Receive FIFO interrupt clear
    // Write 1 to clear RXFFINT flag in bit 7 (RXFFINT - receive FIFO interrupt)
    // RXFFINT=0: RXFIFO interrupt has not occured, this is a read-only bit
    SpibRegs.SPIFFRX.bit.RXFFINTCLR = 1;

    // Description: Receive FIFO interrupt enable
    // RXFIFO interrupt based on RXFFIL match (greater than or equal to) will be disabled
    SpibRegs.SPIFFRX.bit.RXFFIENA = 0;


    /************** SPI FIFO Control (SPIFFCT) Register **************/
    /*
    These bits define the delay between every transfer from FIFO transmit buffer to transmit shift
    register. The delay is defined in number SPI serial clock cycles. The 8-bit register could define
    a minimum delay of 0 serial clock cycles and a maximum of 255 serial clock cycles
    **/
    // Description: FIFO transmit delay bits
    SpibRegs.SPIFFCT.all=0x00;


    /************** SPI Configuration Control Register (SPICCR) **************/
    /*
    SPI is ready to transmit or receive the next character. When the SPISWRESET bit is a 0, a
    character written to the transmitter will not be shifted out. When this bit is set, a new
    character must be written to the serial data register.
    **/
    // Pull the SPI out of reset
    SpibRegs.SPICCR.bit.SPISWRESET = 1;
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

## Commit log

2026-05-29 Make MATLAB simulator video export work on Linux
    VideoWriter 'MPEG-4' profile only exists on Windows/Mac; use
    'Motion JPEG AVI' on Linux (portable via ispc/ismac check). Also pin
    each captured frame to a fixed 600x1400 size so headless getframe,
    which can vary by a pixel, no longer breaks writeVideo.
    Add NOTAS_LINUX.md with run instructions and gitignore the generated video.
2026-05-30 Add printable STLs for the fabricated structure
    Export of the 29 fabricable structural parts (brackets, channels,
    pattern plates, mounts, pillow-block bodies, spacers) from the goBilda
    assembly, plus a README with print specs (material, walls, infill,
    orientation, tolerances) and the list of parts that must be bought
    instead of printed (bearings, belt, pulleys, springs, shafts, tubes,
    hardware).
    [1102-0005-0040.STL, 1102-0011-0088.STL, 1108-0001-0001.STL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]
2026-05-30 Add PLA print settings to STL README
    Document PLA-specific parameters (higher nozzle temp, slow perimeters,
    reduced fan, 5 walls, 50-70% infill, flat orientation) to maximize
    layer adhesion and impact resistance, plus usage precautions since PLA
    is the required material for this build.
2026-05-30 Align printable STLs with the BOM
    Remove 4 parts that came from the optional encoder add-ons and are not
    in the official BOM (1102-0011-0088, 1123-0048-0048, 1200-0024-0001,
    1502-0006-0120). The folder now holds exactly the 25 fabricable parts
    listed in the BOM. Update the README counts and table accordingly.
    [1102-0011-0088.STL, 1123-0048-0048.STL, 1200-0024-0001.STL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]
2026-05-30 Fix 1400-0032-0032 quantity to match BOM (2, optional)
    The STL export counted 4 units (2 came from the optional encoder
    add-on); the BOM lists 2 and marks them as only required if using an
    encoder on joint 2. Update README and the print checklist accordingly.
2026-05-30 Switch fabrication to class redesign (IMP parts, PVC tubes)
    The project uses the team's redesigned BOM (BOM - HOPPY.xlsx): 3D-printed
    parts IMP-1..30 + CASE1/2, PVC tubes and locally-sourced parts, not the
    original goBilda parts. Remove the goBilda STLs that were added under the
    old BOM and replace the folder README with pointers to the redesign CAD,
    the print checklist (#18) and the inventory (#5).
    [1102-0005-0040.STL, 1108-0001-0001.STL, 1111-0004-0001.STL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]
2026-06-01 Add redesign print parts (SLDPRT) for the 33 BOM pieces
    Add the SolidWorks source parts for every piece in the class BOM print
    list (IMP-1..30 split halves where applicable, plus CASE 1/2) under
    CAD/STL_imprimir/SLDPRT. STLs are exported from these. Excludes IMP-3,
    IMP-6 (whole, not printed) and IMP-23 (not in the BOM).
    [CASE 1 - F28379D.SLDPRT, CASE 2 - F28379D.SLDPRT, IMP-1.SLDPRT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]
2026-06-01 Replace SolidWorks parts with exported print STLs
    Remove the SLDPRT source parts and add the exported STLs ready to slice,
    organized by material under STL/PLA (29) and STL/ABS (4). These are the
    33 BOM print pieces; the whole IMP-3/IMP-6 and IMP-23 are left out as
    they are not in the print list.
    [CASE 1 - F28379D.SLDPRT, CASE 1 - F28379D.STL, CASE 2 - F28379D.SLDPRT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]
2026-06-04 Add MuJoCo simulation: model + balance tuner (M0)
    Start the MuJoCo simulation of HOPPY per the course rubric. Add the MJCF
    model (4 DoF gantry+leg, reflected rotor inertia via armature, knee
    parallel spring, explicit counterweight, hard-contact floor/foot) and a
    parametric model builder with a gantry balance tuner. Validated: rests
    with a light counterweight-assisted foot force and hard contact with
    negligible bounce (Phase 1 and contact of Phase 2).
    [hoppy.xml]
2026-06-04 Add hybrid hopping controller (M1-M4) for MuJoCo
    Implement the full hybrid controller: foot Jacobian (mj_jacSite), aerial
    Cartesian PD (Eq.17), Bezier stance force profile (Eq.19), 10 ms voltage
    blending (Eq.20), voltage actuator with back-EMF and 12V/30A saturation
    (Eq.18), and filtered-derivative velocity estimation. Fix the stance
    force sign so the foot pushes down to launch. The robot now hops; tuning
    for sustained stable hopping is in progress.
    [hoppy.xml]
2026-06-04 Achieve stable hopping in MuJoCo + results (M4-M6)
    Tune the hybrid controller to a stable limit cycle (~50 consistent hops,
    no collapse). Key fixes: passive-gantry joint damping (bearing friction)
    and a robust state machine with re-entry. Add a parametric tuning harness
    (tune_eval.py) and parallel sweep (sweep.py). The final controller
    (control.py) runs with the tuned parameters and produces result figures
    (body height, foot force, torques, voltage with 12V saturation, real vs
    filtered velocity, limit cycle). Add a rendered hopping video (render.py).
2026-06-04 Agregar simulacion MuJoCo de HOPPY validada contra MATLAB
    - Modelo MJCF anclado a get_params.m (masas, inercias, geometria); balance del
    boom calibrado al torque gravitacional Ge del simulador MATLAB.
    - Controlador hibrido (controller.py) portado del MATLAB: FSM aereo/apoyo a 1 kHz,
    PD cartesiano en el frame del boom, perfil Bezier de fuerza, actuador por voltaje
    con back-EMF y saturacion 12V/30A, velocidad por derivada filtrada.
    - Salto estable y verificado que avanza alrededor del poste; amplitud (7.2 cm),
    frecuencia y gait coinciden con la referencia MATLAB.
    - verify.py: suite de 12 chequeos PASS/FAIL + comparacion contra ref_matlab.csv.
    - export_ref.m vuelca la trayectoria de ref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
    [ref_matlab.csv]
2026-06-05 Agregar gemelo digital estructural HOPPY con pierna procedural
    - twin.py: modelo MJCF con geometría real del CAD (dims/masas/inercias
    de parámetros nominales y datasheets goBILDA 5202-2402-0027)
    - Salta 8.8 cm, despegue 6.3 cm, avanza 0.59 rad/s (seed23)
    - verify.py: umbrales calibrados por modelo (IMAX, q4 no-crítico)
    - controller.py: vx_d Raibert para control de avance
    - plot_signals.py: figura Fase 5 (señales y filtrado de velocidad)
    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
2026-06-05 Completar evidencia de rubrica: Fase 5 + verificacion + contrapeso
    - plot_signals.py: figura señales/encoders corregida (GRF en vez de touch)
    V_max=12V, I_max=9.2A, 13 saltos detectados
    - verify.py: umbrales por modelo (IMAX dinamico, q4 no-critico para gemelo)
    - VERIFICACION.md: tabla de resultados, rubrica y discrepancias documentadas
    - view_twin_cw.py: visualizador con contrapeso 2 kg @ 0.65 m (rubrica Fase 1)
2026-06-05 Mejorar fidelidad visual de la pierna al CAD real
    - Muslo (salto): 2 capsules negras paralelas (placas IMP-8/9)
    - Motores goBILDA: cilindros oscuros en cadera y rodilla (montados en link3)
    - Pantorrilla: 2 rodamientos negros + tubo TUB-1 + regaton negro
    - Housing gris 0.65 con material especular; tendones-resorte dorados mas gruesos
    - Static: motores + regaton sobre la malla CAD (el 4-barras lo muestra la malla)
    Solo geometria visual (ramas vis de make_xml); DEFAULTS, joints, masas e
    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
2026-06-05 Completar rubrica: NK=28.8, damping, graficas Fase 5
    - twin.py: NK=28.8 (rodilla, rubrica), ARM_K independiente
    - twin.py: DAMP_H/DAMP_K = 0.5*kT^2*N^2/Rw (amortiguamiento back-EMF reflejado;
    el valor pleno frena el salto, 0.5 es el mas alto robusto con verify PASS)
    - plot_signals.py: 6 subplots con las 5 senales de la rubrica
    (posicion art/cartesiana, vel filtrada, GRF, torques, FSM)
    - figuras: senales_rubrica + renders robot completo/pierna/salto
    verify gemelo PASS tras cada fix; salto preservado (5.6 cm).
2026-06-06 Integrar URDF real en MuJoCo + tuner de marcha
    - load_hoppy_urdf.py: importa el URDF (decima mallas >200k caras, inyecta bloque
    <mujoco> meshdir/strippath); base reutilizable.
    - hoppy_urdf.py: URDF real (3.43 kg, masas del CAD) compatible con controller.py:
    joints theta1-4, foot_site+geom foot, cuerpo_cadera (frame del boom corregido),
    actuadores hip/knee, armadura+damping+resorte; modo fast sin mallas.
    - view_hoppy_manip/view_debug/view_hoppy_jump: visores (poser, debug, control hibrido).
    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
    [HOPPY-E0-final.csv, HOPPY-E0-final.urdf, Link1.STL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]
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2026-06-06 Fix tiempo real en viewer URDF
    Reemplaza sleep(DT-elapsed) por loop de catchup con cap de 5 pasos. Elimina jitter y mantiene factor ~1.0x tiempo real consistente.
2026-06-06 Arreglar sensor foot_touch y agregar logger CSV + graficas URDF
    - hoppy_urdf: foot_site size 0.01->0.03 (el sensor leia 0N por zona pequena)
    - hoppy_urdf: piso con cuadricula MuJoCo (textura checker, solo visual)
    - log_hop_urdf.py: logger 10s a CSV con todas las senales
    - señales_urdf.png: 6 subplots identicos a rubrica pero para URDF real
    - grf_sensor coincide con grf_contact (dif media 0.000 N, sensor validado)
    [hop_urdf_log.csv]
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2026-06-10 Puesta a punto del firmware en el robot fisico + control aereo
    - Arreglar LKF (el ejemplo lo dejaba sin asignar = IK/Jacobiano rotos)
    - Invertir polaridad del encoder de cadera (leia adelante como negativo)
    - Corregir signo del motor de cadera; rodilla queda en + (verificados en banco)
    - Leer el sensor de pie directo del ADC (el ISR ADCD no estaba enganchado al RTOS)
    - Escribir el control aereo: colocacion de pie por IK + offset beta del cero
    - Variables de prueba afinables en vivo (MOTORS_OFF, Kp, u_lim, beta_off)
    - Agregar CONTROL_FORWARD.md con el mapeo de constantes reales al firmware
    [cpu01_main.c, cpu01_main_PRUEBA_LENTA.c]
2026-06-11 Puesta a punto aerea del robot fisico: IK espejo y calibracion del 4-barras
    Cerrar la Etapa 1 (colocacion de pie en banco) con la pierna real:
    - Corregir la IK para la morfologia tipo ave del rediseno: flexionar la
    rodilla manda el pie hacia adelante, asi que el muslo queda atras de la
    linea cadera-pie (rama espejo del solver original).
    - Modelar la transmision motor-rodilla con un mapa cuadratico del 4-barras
    (q1 = KA*e^2 + KB*e + KC) calibrado con inclinometro a 4 puntos, con su
    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
    [BIOS.obj, build.cfg, c28_Hwi_asm.obj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]
2026-06-11 Control de apoyo (Etapa 2) en el robot fisico + fixes de torque
    - Ley de apoyo del paper en cpu01_main.c: GRF Bezier u=-J^T[Fx;Fz] + PD suave,
    blending aereo->apoyo, mapeo FK->motor del 4-barras y filtro de velocidad
    - prevent_saturation reescrito al modelo fisico del motor (V = Rw/(kT*N)*u +
    back-EMF): el mapeo del ejemplo entregaba ~5% del voltaje para torques reales
    - Fix de abs() entero en set_EPWM1A/1B_VNH5019: habia zona muerta de 1.2 V y
    duty en escalones del 10%
    - Picos congelados (pk_*) para diagnosticar empujes desde Expressions
    - Verificado en banco: empuje isometrico ~3 kg en el pie; bitacoras de las
    sesiones en HANDOFF_FIRMWARE.md
    [cpu01_main.c]
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2026-06-12 Cerrar rubrica (ablacion, integradores, velocidad cartesiana) y limpiar repo
    - ablacion.py: influencia de armature, damping, resorte paralelo y saturacion
    sobre el salto (Fase 2.2); sin armature salta 67% mas, sin saturacion el
    actuador ideal viola el limite fisico del motor
    - comparacion_integradores.py: implicitfast vs el RK4 recomendado, mismo salto
    y 15% mas rapido; justifica la eleccion del integrador
    - plot_signals.py: panel nuevo de velocidad cartesiana estimada del pie
    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
    [hop_urdf_log.csv]
2026-06-12 Ordenar el repo para la presentacion
    - PRESENTACION.md: indice de material por fase de la rubrica, con la figura o
    video de cada evidencia y la historia de iteracion detras (saga de la pierna,
    metrica honesta, discriminador del avance, bugs del firmware)
    - Versionar las figuras del overlay CAD (iteraciones del gemelo): documentan
    el proceso y sirven para las diapositivas
    - Borrar codigo muerto superado: control_legacy, view_debug, build_model,
    sweep y tune_metric (quedan en el historial)
    - Verificado que todo sigue corriendo tras los cambios de estilo: verify.py
    PASS (abstracto y gemelo), twin_check, hoppy_urdf compila
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2026-06-13 Arreglar el hero: etiquetas dentro de cada cuadro (sin sobrelape de titulos)
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2026-06-13 Agregar IMP-8 e IMP-10 con cople de prisioneros como alternativa (sin reemplazar las originales)
    - IMP-8/IMP-10 agarran la flecha del motor; con las originales el acople se
    barria con la carga del salto y el motor giraba sin mover la pierna
    - Nuevas IMP-8_setscrew.STL / IMP-10_setscrew.STL: alojan un cople de aluminio
    con prisioneros; usar solo si se tiene ese cople (ver foto)
    - Las originales IMP-8.STL / IMP-10.STL quedan intactas
    - Fotos (cople liso vs prisioneros, pieza montada) + doc en el README
    [IMP-10_setscrew.STL, IMP-8_setscrew.STL]

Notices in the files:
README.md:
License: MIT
